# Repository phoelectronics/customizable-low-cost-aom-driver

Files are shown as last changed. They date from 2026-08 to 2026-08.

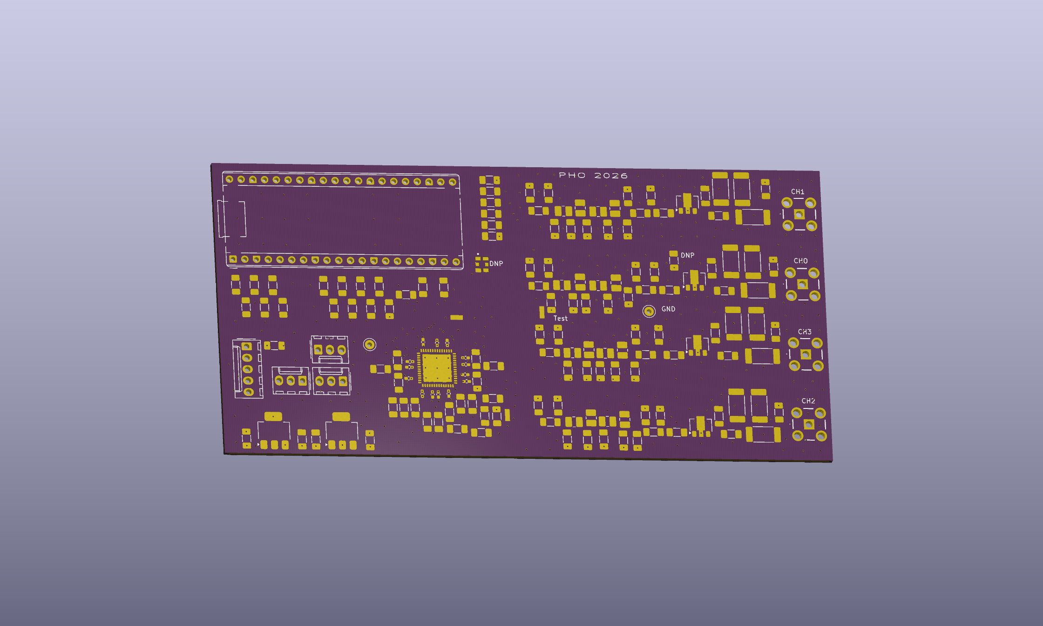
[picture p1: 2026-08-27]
lcg_pcb_bare.png

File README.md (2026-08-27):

# customizable-low-cost-aom-driver
Designed by Parker Osborne, University of San Diego
A custom low-cost four-channel RF signal generator that costs about $250 per board. Built around an Analog Devices AD9959 direct digital synthesizer, clocked and controlled by a raspberry Pi Pico 2W (RP2350). Features per channel: 9th order Nyquist image suppression filter, resistive pads for match and flatness, monolithic amplifier stage, +10 dBm delivered at SMA output. Tuned for 50-150 MHz output band.

The low-cost gen is built on a 4-layer RF PCB, fabricated by OSHPark. Note: When the PCB was order for the current version, a supply shortage led to a non-standard insulating core being used in this design, compared to the usual service. A stencil used for soldering the AD9959 and surround decoupling capacitors was ordered from OSH Stencils. Everything was assembled by hand using a soldering iron, hotplate, and digital microscope.

Current Version and Notes:
The low-cost generator is currently in its first working version. A second version is currently planned, with noted changes below. This design is open source and intended to be used for atomic, molecular, and optics physics, but can be implemented in a wide variety of fields. We are currently using it for doppler cooling Rb-87 atoms to create Bose-Einstein condensates. 

Current software control is limited to basic testing functions, routines can be written and triggered using spare Pico GPIO pins but are not provided here.

A full proceedings paper write up is currently planned and will be added here when completed. Currently in the final testing phase of the first design.

Note: A power supply failure burnt out the synthesizer while testing in the current version. It is suggested to remove the Vsys Pin (39) from the Raspberry Pi Pico if communication over USB serial is to be used. 

Changes for Version 2:
- adding power supply protection
- adding current limiting resistor of chip select line 
- shrinking package size of capacitors in filter

  Please reach out to me if you have any questions.

lcg_pcb_banner

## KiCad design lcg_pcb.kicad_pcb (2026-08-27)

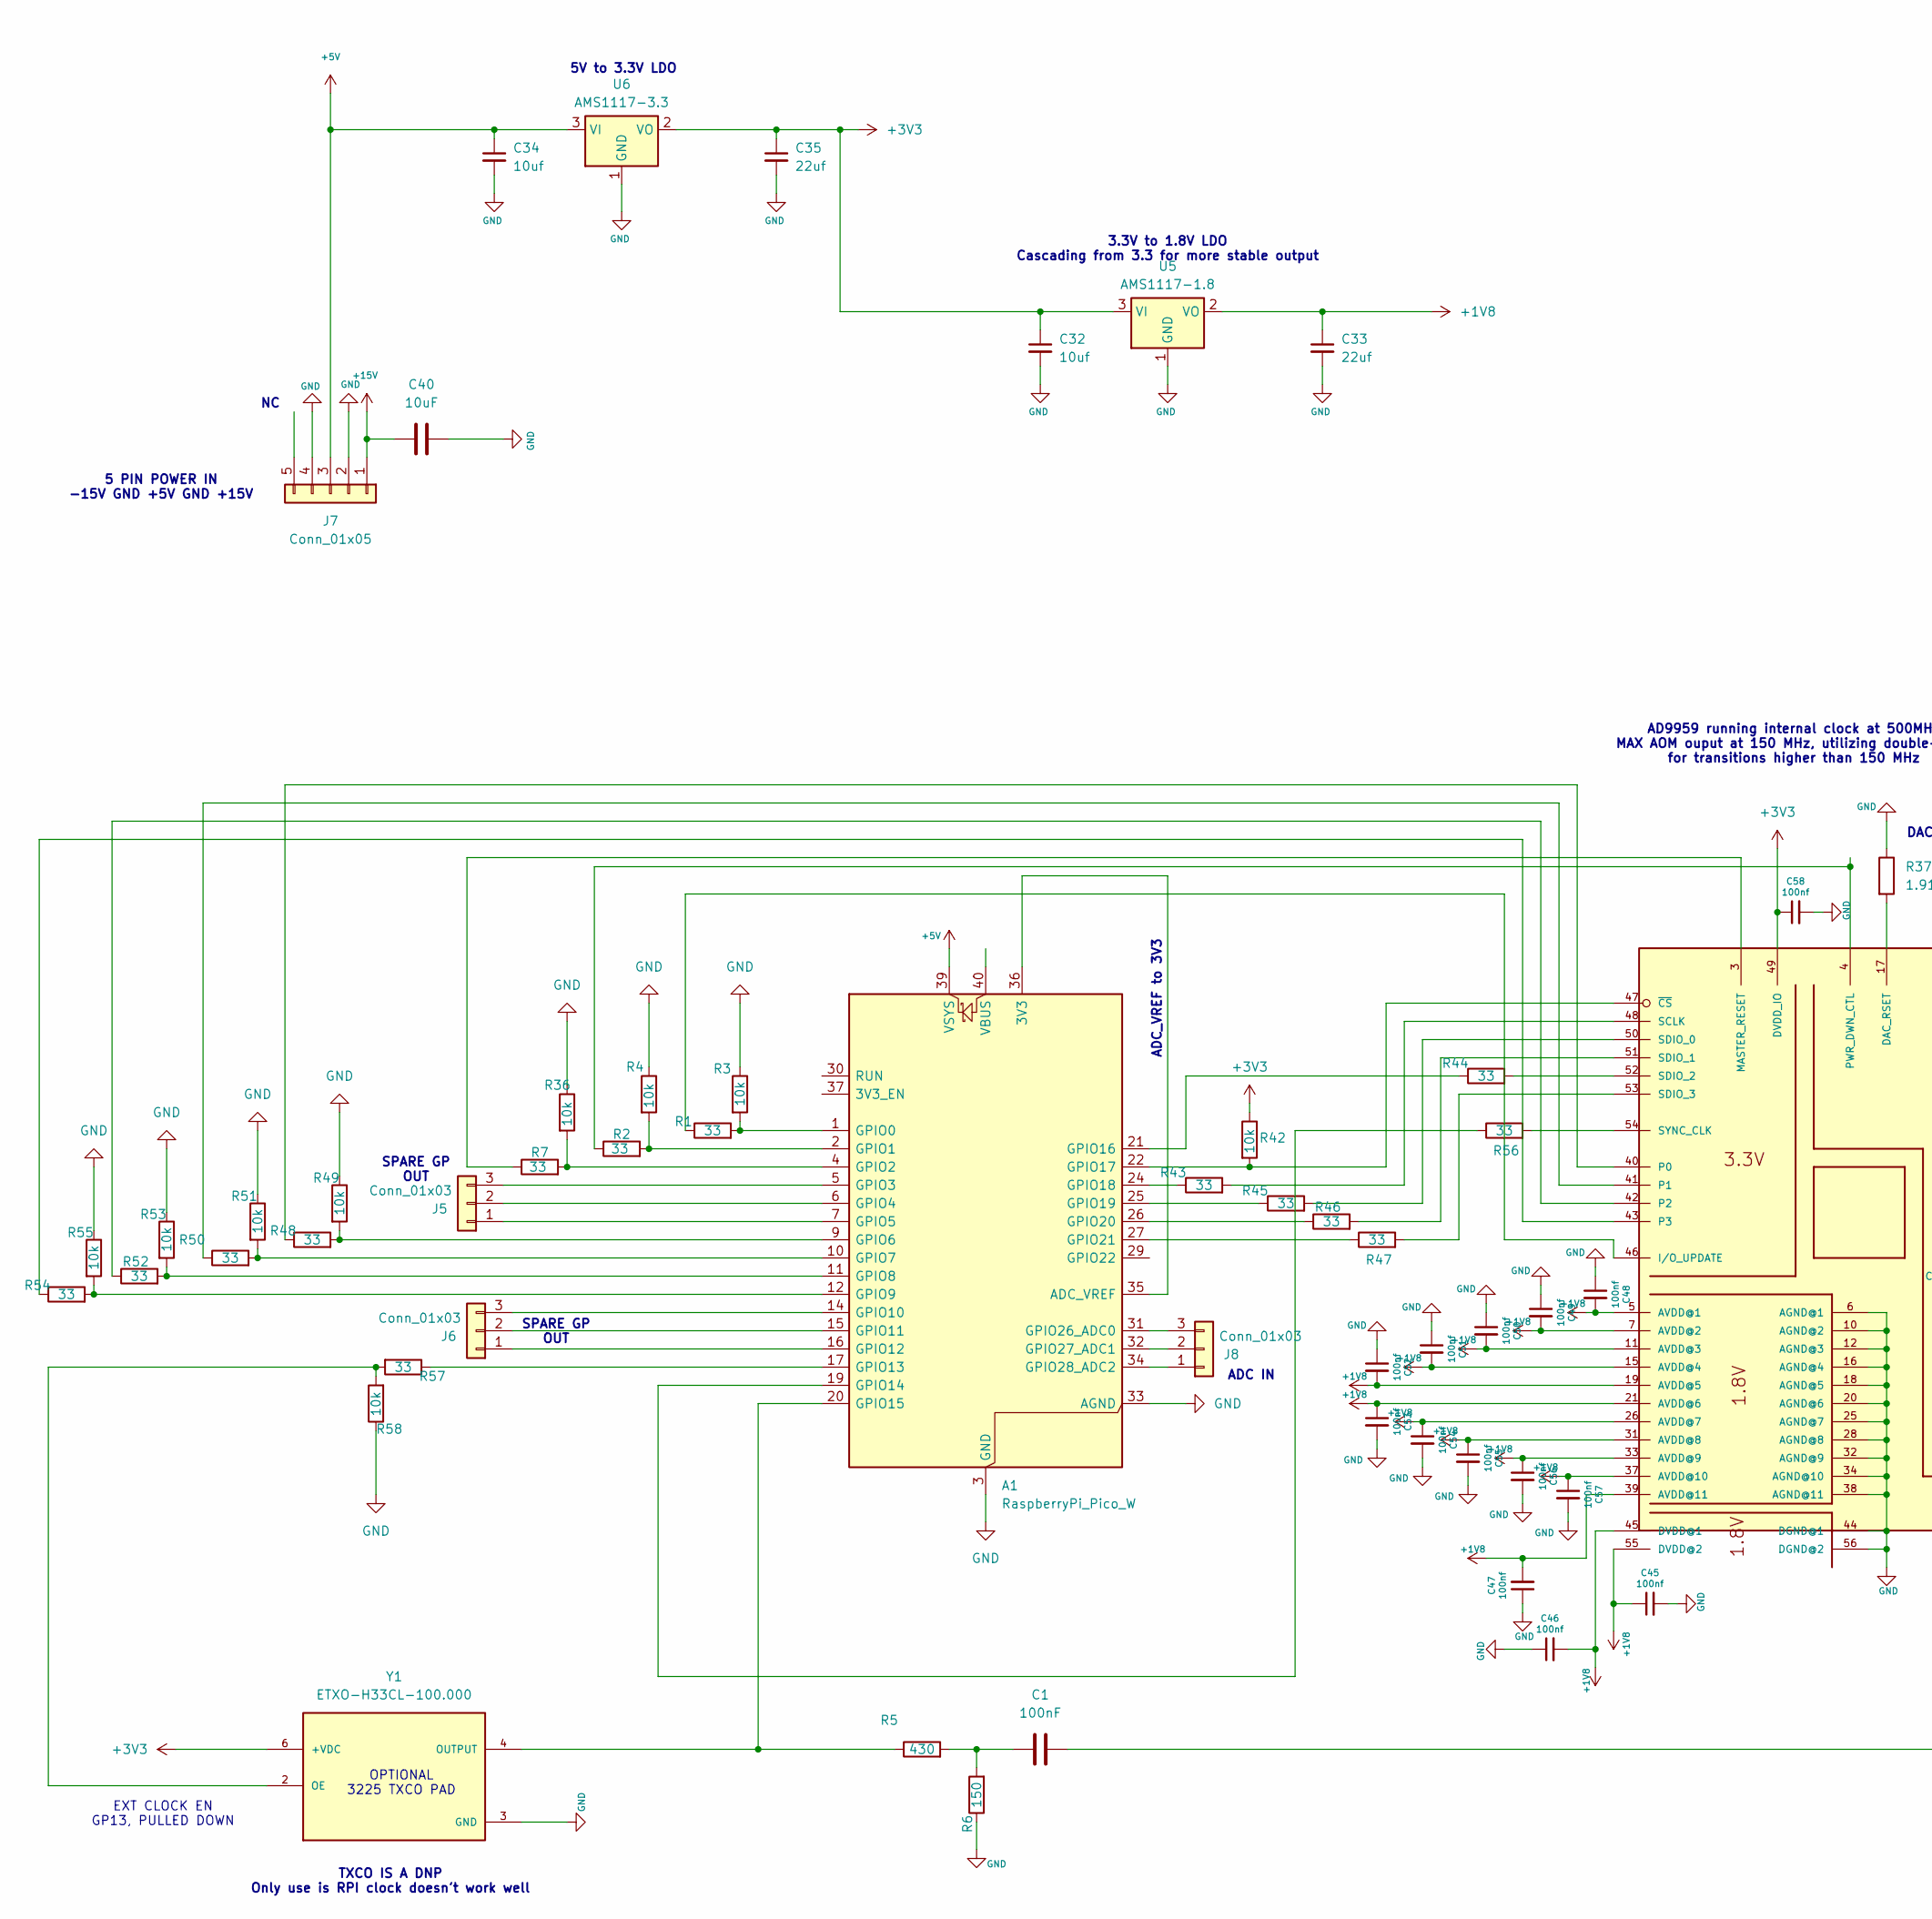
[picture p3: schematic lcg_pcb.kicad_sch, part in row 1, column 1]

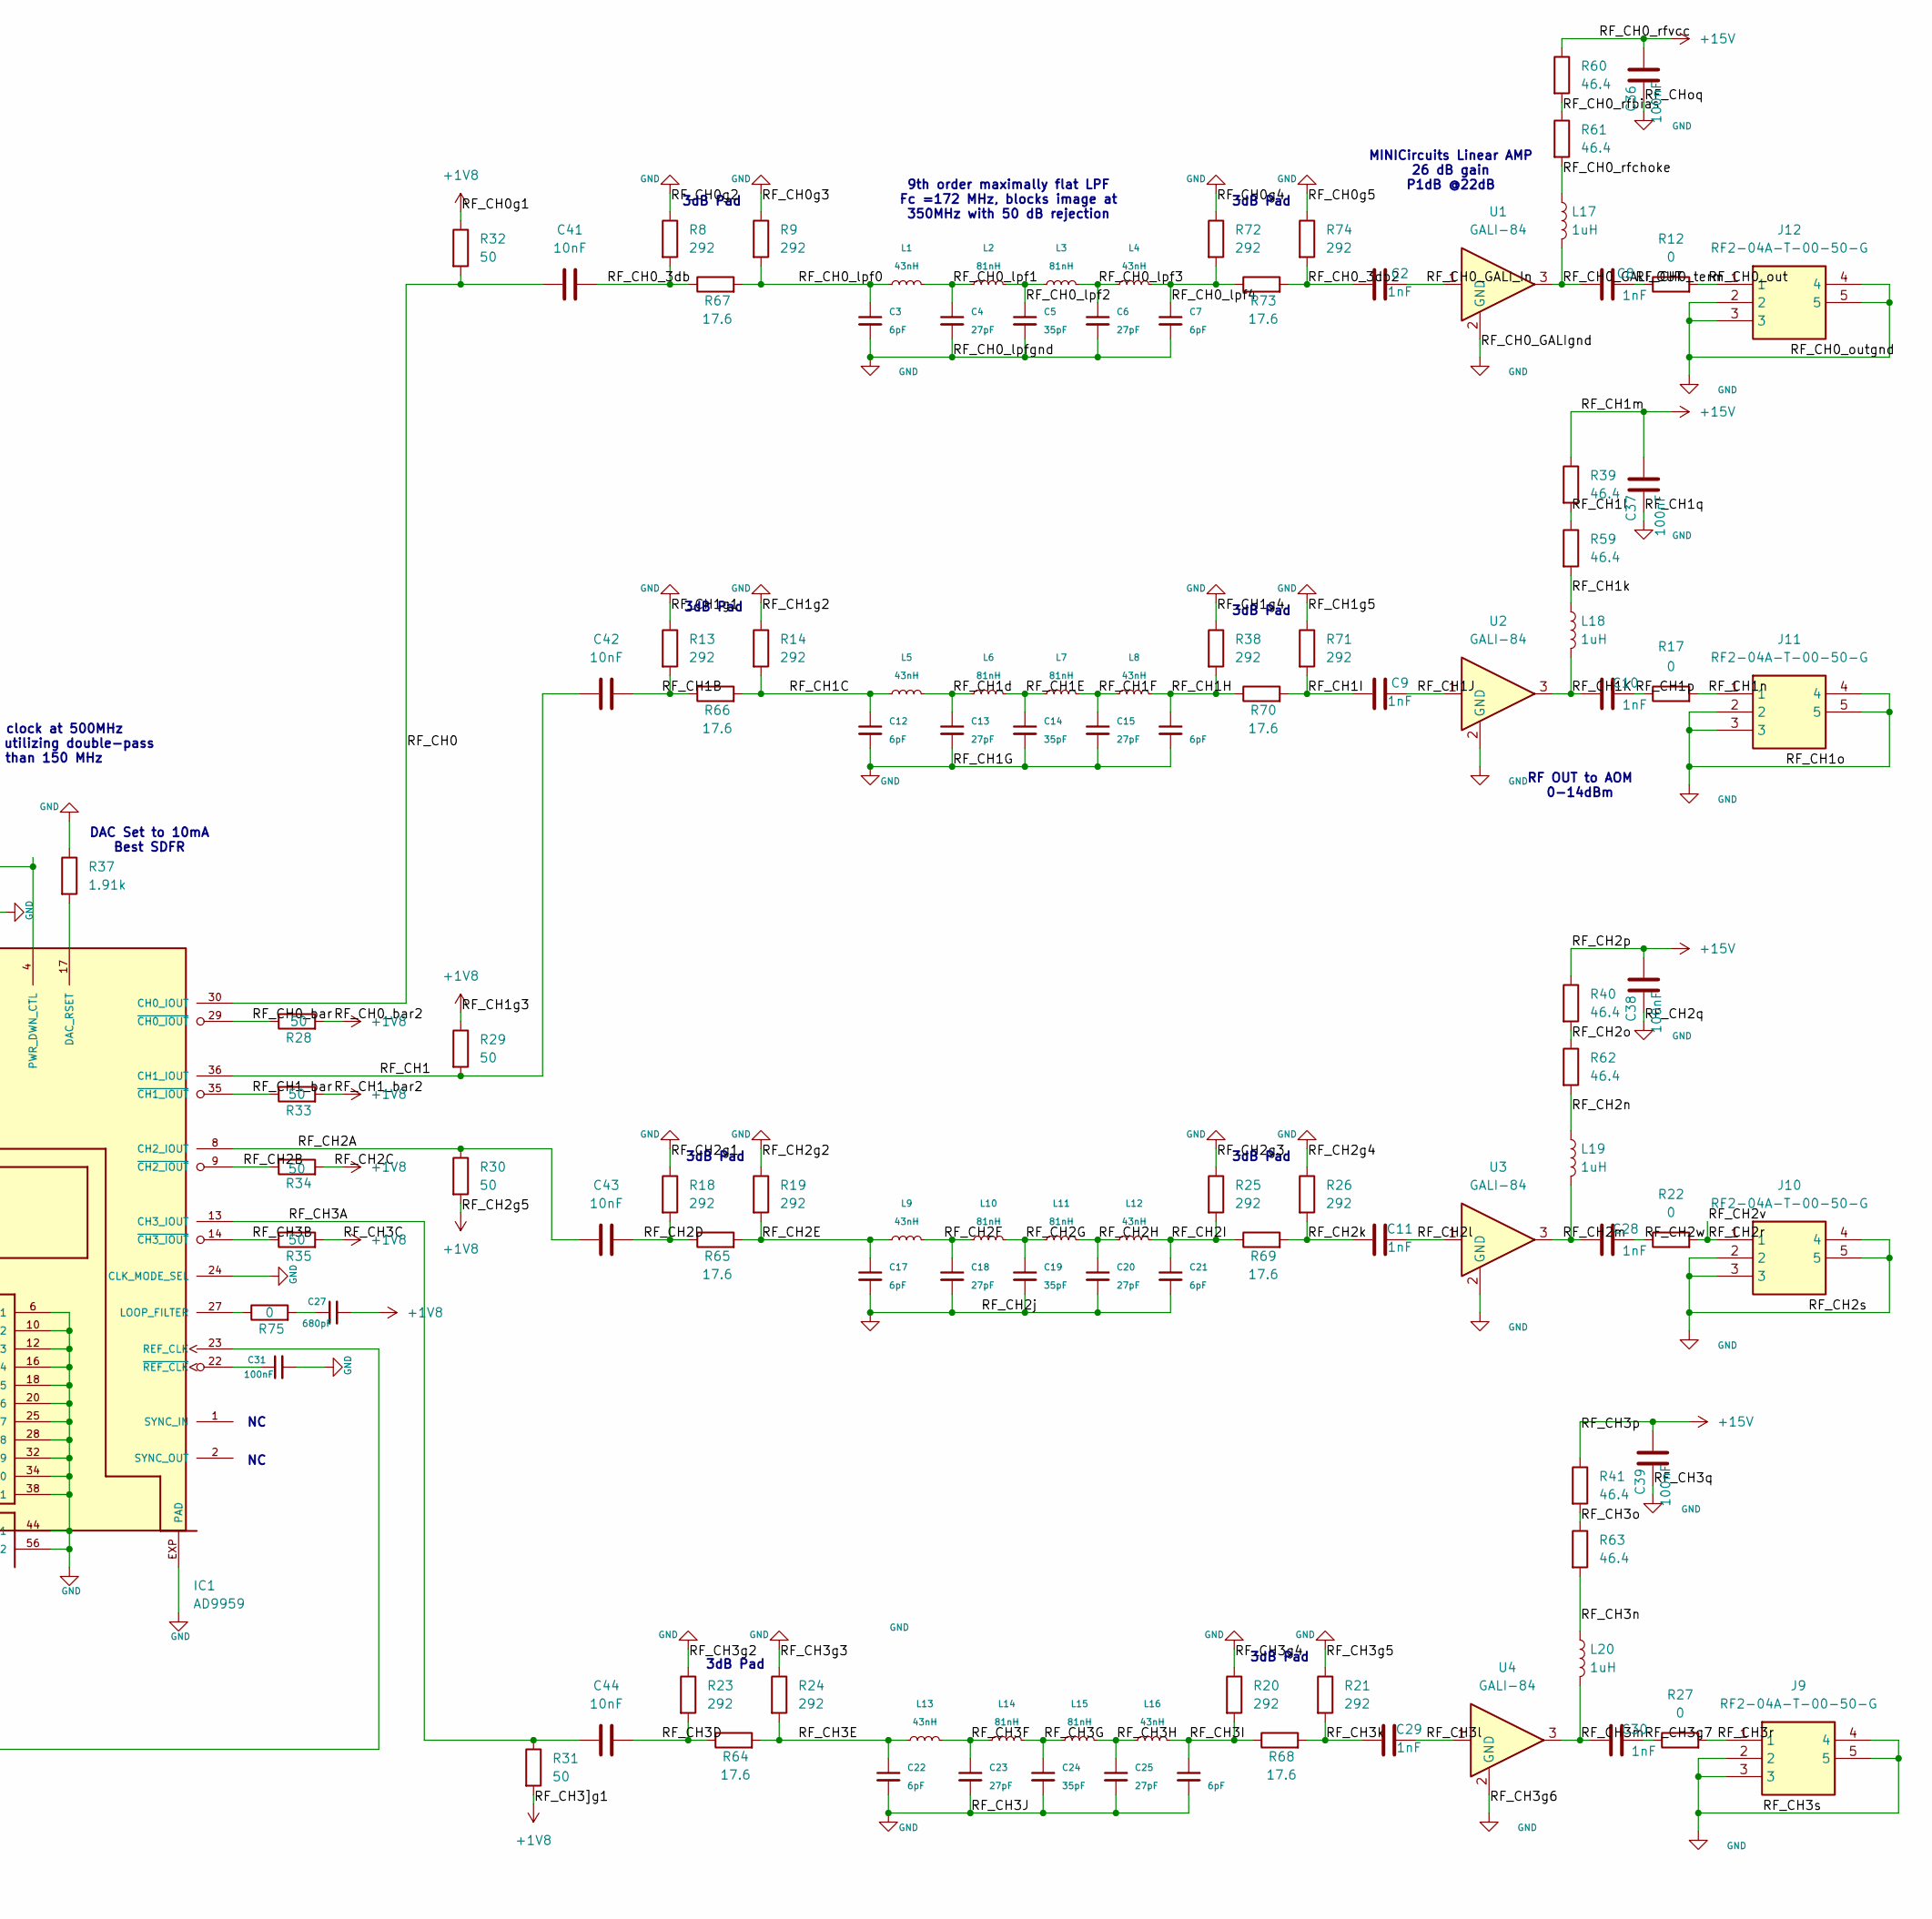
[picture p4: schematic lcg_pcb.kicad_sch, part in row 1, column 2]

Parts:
A1: RaspberryPi_Pico_W; RaspberryPi_Pico_Common_THT
C1, C31, C36, C37, C38, C39: 100nF; C_1206_3216Metric_Pad1.33x1.80mm_HandSolder
C2, C8, C9, C10, C11, C28, C29, C30: 1nF; C_1206_3216Metric_Pad1.33x1.80mm_HandSolder
C3, C7, C12, C16, C17, C21, C22, C26: 6pF; C_1206_3216Metric_Pad1.33x1.80mm_HandSolder
C4, C6, C13, C15, C18, C20, C23, C25: 27pF; C_1206_3216Metric_Pad1.33x1.80mm_HandSolder
C5, C14, C19, C24: 35pF; C_1206_3216Metric_Pad1.33x1.80mm_HandSolder
C27: 680pF; C_1206_3216Metric_Pad1.33x1.80mm_HandSolder
C32, C34: 10uf; C_1206_3216Metric_Pad1.33x1.80mm_HandSolder
C33, C35: 22uf; C_1206_3216Metric_Pad1.33x1.80mm_HandSolder
C40: 10uF; C_1206_3216Metric_Pad1.33x1.80mm_HandSolder
C41, C42, C43, C44: 10nF; C_1206_3216Metric_Pad1.33x1.80mm_HandSolder
C45, C46, C47, C48, C49, C50, C51, C52, C53, C54, C55, C56, C57, C58: 100nf; C_0402_1005Metric_Pad0.74x0.62mm_HandSolder
IC1: AD9959; LFCSP56
J5, J6, J8: Conn_01x03; Molex_KK-254_AE-6410-03A_1x03_P2.54mm_Vertical
J7: Conn_01x05; Molex_KK-254_AE-6410-05A_1x05_P2.54mm_Vertical
J9, J10, J11, J12: RF2-04A-T-00-50-G; RF204AT0050G; Mouser Part Number 737-RF204AT0050G
L1, L4, L5, L8, L9, L12, L13, L16: 43nH; L_1008_2520Metric_Pad1.43x2.20mm_HandSolder
L2, L3, L6, L7, L10, L11, L14, L15: 81nH; L_1008_2520Metric_Pad1.43x2.20mm_HandSolder
L17, L18, L19, L20: 1uH; L_1206_3216Metric_Pad1.22x1.90mm_HandSolder
R1, R2, R7, R43, R44, R45, R46, R47, R48, R50, R52, R54, R56, R57: 33; R_1206_3216Metric_Pad1.30x1.75mm_HandSolder
R3, R4, R36, R42, R49, R51, R53, R55, R58: 10k; R_1206_3216Metric_Pad1.30x1.75mm_HandSolder
R5: 430; R_1206_3216Metric_Pad1.30x1.75mm_HandSolder
R6: 150; R_1206_3216Metric_Pad1.30x1.75mm_HandSolder
R8, R9, R13, R14, R18, R19, R20, R21, R23, R24, R25, R26, R38, R71, R72, R74: 292; R_1206_3216Metric_Pad1.30x1.75mm_HandSolder
R12, R17, R22, R27: 0; R_2512_6332Metric_Pad1.40x3.35mm_HandSolder
R28, R29, R30, R31, R32, R33, R34, R35: 50; R_1206_3216Metric_Pad1.30x1.75mm_HandSolder
R37: 1.91k; R_1206_3216Metric_Pad1.30x1.75mm_HandSolder
R39, R40, R41, R59, R60, R61, R62, R63: 46.4; R_2512_6332Metric_Pad1.40x3.35mm_HandSolder
R64, R65, R66, R67, R68, R69, R70, R73: 17.6; R_1206_3216Metric_Pad1.30x1.75mm_HandSolder
R75: 0; R_1206_3216Metric_Pad1.30x1.75mm_HandSolder
U1, U2, U3, U4: GALI-84; SOT-89-3
U5: AMS1117-1.8; SOT-223-3_TabPin2
U6: AMS1117-3.3; SOT-223-3_TabPin2
Y1: ETXO-H33CL-100.000; OSC_ETXO-H33CL-100.000

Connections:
+1V8: C27.2, C33.1, C45.1, C46.2, C47.2, C48.2, C49.2, C50.2, C51.2, C52.2, C53.1, C54.1, C55.1, C56.1, C57.1, IC1.5 (AVDD@1), IC1.7 (AVDD@2), IC1.11 (AVDD@3), IC1.15 (AVDD@4), IC1.19 (AVDD@5), IC1.21 (AVDD@6), IC1.26 (AVDD@7), IC1.31 (AVDD@8), IC1.33 (AVDD@9), IC1.37 (AVDD@10), IC1.39 (AVDD@11), IC1.45 (DVDD@1), IC1.55 (DVDD@2), R28.2, R29.1, R30.2, R31.2, R32.1, R33.2, R34.2, R35.2, U5.2 (VO)
+3V3: C32.1, C35.1, C58.1, IC1.49 (DVDD_IO), R42.1, U5.3 (VI), U6.2 (VO), Y1.6 (+VDC)
+5V: A1.39 (VSYS), C34.1, J7.3, U6.3 (VI)
+15V: C36.2, C37.2, C38.2, C39.2, C40.2, J7.1, R39.1, R40.1, R41.1, R60.1; also elsewhere on the board
/RF_CH0: C41.1, IC1.30 (CH0_IOUT), R32.2
/RF_CH0_3db: C41.2, R8.2, R67.1; also elsewhere on the board
/RF_CH0_3db2: C2.1, R73.2, R74.2
/RF_CH0_GALI_In: C2.2, U1.1
/RF_CH0_GALI_OUT: C8.1, L17.2, U1.3
/RF_CH0_bar: IC1.29 (~CH0_IOUT), R28.1
/RF_CH0_lpf0: C3.1, L1.1, R9.2, R67.2
/RF_CH0_lpf1: C4.1, L1.2, L2.1
/RF_CH0_lpf2: C5.1, L2.2, L3.1
/RF_CH0_lpf3: C6.1, L3.2, L4.1
/RF_CH0_lpf4: C7.1, L4.2, R72.2, R73.1
/RF_CH0_out: J12.1, R12.2
/RF_CH0_rfbias: R60.2, R61.1
/RF_CH0_rfchoke: L17.1, R61.2
/RF_CH0_term: C8.2, R12.1
/RF_CH1: C42.1, IC1.36 (CH1_IOUT), R29.2
/RF_CH1B: C42.2, R13.2, R66.1
/RF_CH1C: C12.1, L5.1, R14.2, R66.2
/RF_CH1E: C14.1, L6.2, L7.1
/RF_CH1F: C15.1, L7.2, L8.1
/RF_CH1H: C16.1, L8.2, R38.2, R70.1
/RF_CH1I: C9.1, R70.2, R71.2
/RF_CH1J: C9.2, U2.1
/RF_CH1K: C10.1, L18.2, U2.3
/RF_CH1_bar: IC1.35 (~CH1_IOUT), R33.1
/RF_CH1d: C13.1, L5.2, L6.1
/RF_CH1k: L18.1, R59.2
/RF_CH1l: R39.2, R59.1
/RF_CH1n: J11.1, R17.2
/RF_CH1p: C10.2, R17.1
/RF_CH2A: C43.1, IC1.8 (CH2_IOUT), R30.1
/RF_CH2B: IC1.9 (~CH2_IOUT), R34.1
/RF_CH2D: C43.2, R18.2, R65.1
/RF_CH2E: C17.1, L9.1, R19.2, R65.2
/RF_CH2F: C18.1, L9.2, L10.1
/RF_CH2G: C19.1, L10.2, L11.1
/RF_CH2H: C20.1, L11.2, L12.1
/RF_CH2I: C21.1, L12.2, R25.2, R69.1
/RF_CH2k: C11.1, R26.2, R69.2
/RF_CH2l: C11.2, U3.1
/RF_CH2m: C28.1, L19.2, U3.3
/RF_CH2n: L19.1, R62.2
/RF_CH2o: R40.2, R62.1
/RF_CH2r: J10.1, R22.2
/RF_CH2w: C28.2, R22.1
/RF_CH3A: C44.1, IC1.13 (CH3_IOUT), R31.1
/RF_CH3B: IC1.14 (~CH3_IOUT), R35.1
/RF_CH3D: C44.2, R23.2, R64.1
/RF_CH3E: C22.1, L13.1, R24.2, R64.2
/RF_CH3F: C23.1, L13.2, L14.1
/RF_CH3G: C24.1, L14.2, L15.1
/RF_CH3H: C25.1, L15.2, L16.1
/RF_CH3I: C26.1, L16.2, R20.2, R68.1
/RF_CH3g7: C30.2, R27.1
/RF_CH3k: C29.1, R21.2, R68.2
/RF_CH3l: C29.2, U4.1
/RF_CH3m: C30.1, L20.2, U4.3
/RF_CH3n: L20.1, R63.2
/RF_CH3o: R41.2, R63.1
/RF_CH3r: J9.1, R27.2
GND: A1.3 (GND), A1.8 (GND), A1.13 (GND), A1.18 (GND), A1.23 (GND), A1.28 (GND), A1.33 (AGND), A1.38 (GND), C3.2, C4.2, C5.2, C6.2, C7.2, C12.2, C13.2, C14.2, C15.2, C16.2, C17.2, C18.2, C19.2, C20.2, C21.2, C22.2, C23.2, C24.2, C25.2, C26.2, C31.2, C32.2, C33.2, C34.2, C35.2, C36.1, C37.1, C38.1, C39.1, C40.1, C45.2, C46.1, C47.1, C48.1, C49.1, C50.1, C51.1, C52.1, C53.2, C54.2, C55.2, C56.2, C57.2, C58.2, IC1.6 (AGND@1), IC1.10 (AGND@2), IC1.12 (AGND@3), IC1.16 (AGND@4), IC1.18 (AGND@5), IC1.20 (AGND@6), IC1.24 (CLK_MODE_SEL), IC1.25 (AGND@7), IC1.28 (AGND@8), IC1.32 (AGND@9), IC1.34 (AGND@10), IC1.38 (AGND@11), IC1.44 (DGND@1), IC1.56 (DGND@2), IC1.EXP (PAD), J7.2, J7.4, J9.2, J9.3, J9.4, J9.5, J10.2, J10.3, J10.4, J10.5, J11.2, J11.3, J11.4, J11.5, J12.2, J12.3, J12.4, J12.5, R3.1, R4.1, R6.1, R8.1, R9.1, R13.1, R14.1, R18.1, R19.1, R20.1, R21.1, R23.1, R24.1, R25.1, R26.1, R36.1, R37.1, R38.1, R49.1, R51.1, R53.1, R55.1, R58.1, R71.1, R72.1, R74.1, U1.2 (GND_2), U2.2 (GND_2), U3.2 (GND_2), U4.2 (GND_2), U5.1 (GND), U6.1 (GND), Y1.3 (GND); also elsewhere on the board
unnamed: A1.35 (ADC_VREF), A1.36 (3V3)
unnamed: A1.1 (GPIO0), R1.2, R3.2
unnamed: A1.2 (GPIO1), R2.2, R4.2
unnamed: A1.4 (GPIO2), R7.2, R36.2
unnamed: A1.5 (GPIO3), J5.3
unnamed: A1.6 (GPIO4), J5.2
unnamed: A1.7 (GPIO5), J5.1
unnamed: A1.9 (GPIO6), R48.2, R49.2
unnamed: A1.10 (GPIO7), R50.2, R51.2
unnamed: A1.11 (GPIO8), R52.2, R53.2
unnamed: A1.12 (GPIO9), R54.2, R55.2
unnamed: A1.14 (GPIO10), J6.3
unnamed: A1.15 (GPIO11), J6.2
unnamed: A1.16 (GPIO12), J6.1
unnamed: A1.17 (GPIO13), R57.1
unnamed: A1.19 (GPIO14), R56.1
unnamed: A1.20 (GPIO15), R5.1, Y1.4 (OUTPUT)
unnamed: A1.21 (GPIO16), R44.1
unnamed: A1.22 (GPIO17), IC1.47 (~CS), R42.2
unnamed: A1.24 (GPIO18), R43.1
unnamed: A1.25 (GPIO19), R45.1
unnamed: A1.26 (GPIO20), R46.1
unnamed: A1.27 (GPIO21), R47.1
unnamed: A1.31 (GPIO26_ADC0), J8.3
unnamed: A1.32 (GPIO27_ADC1), J8.2
unnamed: A1.34 (GPIO28_ADC2), J8.1
unnamed: C1.1, R5.2, R6.2
unnamed: C27.1, R75.2
unnamed: IC1.17 (DAC_RSET), R37.2
unnamed: IC1.46 (I/O_UPDATE), R1.1
unnamed: IC1.27 (LOOP_FILTER), R75.1
unnamed: IC1.3 (MASTER_RESET), R7.1
unnamed: IC1.40 (P0), R48.1
unnamed: IC1.41 (P1), R50.1
unnamed: IC1.42 (P2), R52.1
unnamed: IC1.43 (P3), R54.1
unnamed: IC1.4 (PWR_DWN_CTL), R2.1
unnamed 102: C1.2, IC1.23 (REF_CLK); also elsewhere on the board
unnamed: IC1.48 (SCLK), R43.2
unnamed 104: IC1.50 (SDIO_0), R45.2; also elsewhere on the board
unnamed: IC1.51 (SDIO_1), R46.2
unnamed: IC1.52 (SDIO_2), R44.2
unnamed: IC1.53 (SDIO_3), R47.2
unnamed: IC1.54 (SYNC_CLK), R56.2
unnamed: C31.1, IC1.22 (~REF_CLK)
unnamed: R57.2, R58.2, Y1.2 (OE)

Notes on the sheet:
ADC IN
DAC Set to 10mA Best SDFR
3dB Pad
ADC_VREF to 3V3
MINICircuits Linear AMP 26 dB gain P1dB @22dB
9th order maximally flat LPF Fc =172 MHz, blocks image at 350MHz with 50 dB rejection
SPARE GP OUT
3.3V to 1.8V LDO Cascading from 3.3 for more stable output
OPTIONAL 3225 TXCO PAD
AD9959 running internal clock at 500MHz MAX AOM ouput at 150 MHz, utilizing double-pass for transitions higher than 150 MHz
5 PIN POWER IN -15V GND +5V GND +15V
RF OUT to AOM 0-14dBm
EXT CLOCK EN GP13, PULLED DOWN
5V to 3.3V LDO
TXCO IS A DNP Only use is RPI clock doesn't work well

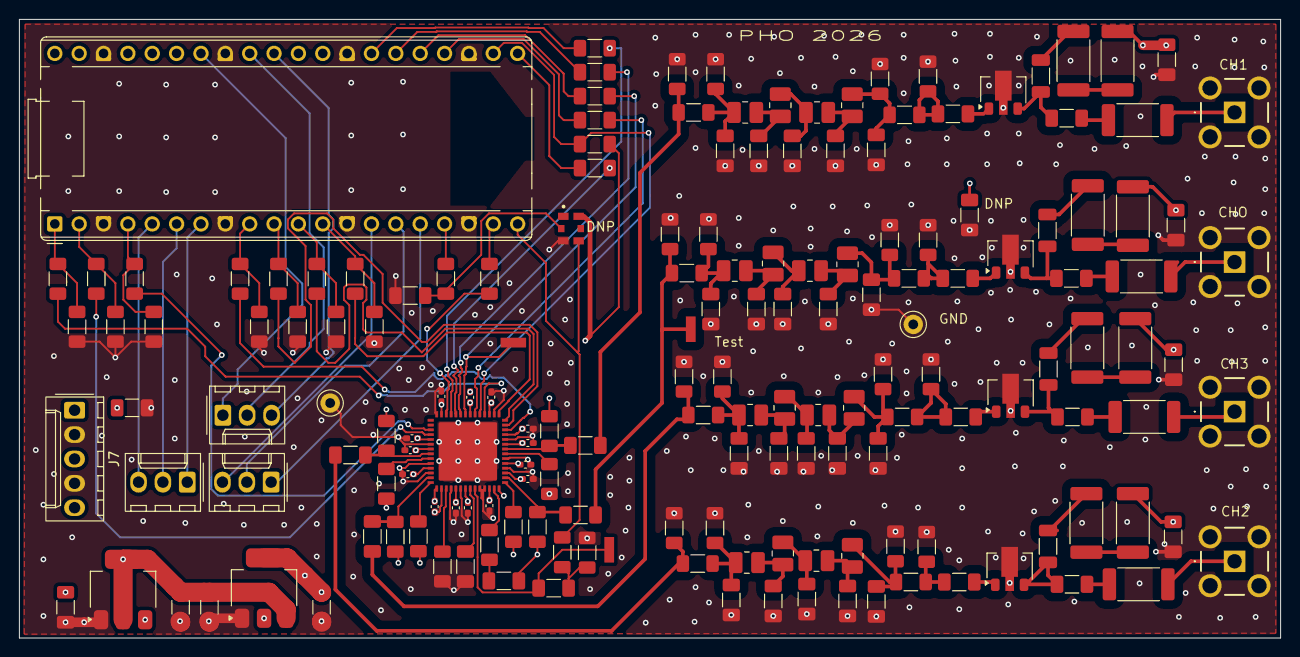
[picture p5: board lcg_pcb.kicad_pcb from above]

Board: 4 copper layers, 131.5 x 64.5 mm, 172 parts (0 on the bottom side), 111 nets.

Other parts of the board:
C59: 10uF; C_1206_3216Metric_Pad1.33x1.80mm_HandSolder
TP2, TP4, TP5: 5015; Test_Point_2.67x1.02mm
TP6, TP7: 5001; Test_Point_D1.02mm

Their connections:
+15V: C59.2; also elsewhere on the board
/RF_CH0_3db: TP2.1 (~_1); also elsewhere on the board
GND: C59.1, TP6.1 (~_1), TP7.1 (~_1); also elsewhere on the board
unnamed 102: TP4.1 (~_1); also elsewhere on the board
unnamed 104: TP5.1 (~_1); also elsewhere on the board
